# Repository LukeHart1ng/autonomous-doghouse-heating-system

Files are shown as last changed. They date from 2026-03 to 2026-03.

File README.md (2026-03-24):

# Autonomous Doghouse Heating System

A fully autonomous embedded temperature control system designed to regulate a 12V heating pad inside an outdoor doghouse. Built from the ground up — from requirements and schematic capture through custom PCB fabrication, firmware development, and structured verification testing.

## System Overview

The system activates a heating pad when ambient temperature falls between 0°F and 40°F and deactivates it when the temperature rises above that range. A secondary sensor monitors the heating pad surface and limits output if it approaches 115°F, preventing thermal overshoot. Heating intensity is regulated using a proportional PWM algorithm.

**Key specs:**
- Activation range: 0°F to 40°F (±2°F tolerance)
- Pad temperature limit: 115°F
- Activation response time: <30 seconds
- Sensor accuracy: ±2°F (verified against calibrated IR thermometer)
- Input power: 12V DC (compatible with battery or solar supply)
- Total system power: <50W

## Hardware Architecture

| Component | Part | Purpose |
|---|---|---|
| Microcontroller | MSP430FR2310 | Control logic, ADC, PWM generation |
| Temperature sensors | TMP36 (x2) | Ambient air + heating pad surface |
| Power switching | AO3400A N-channel MOSFET | Low-side switch for heating pad |
| Power regulation | LM2594MX-3.3 buck converter | 12V → 3.3V for MCU and sensors |
| Heating element | 12V DC heating pad | Primary heat source |
| Protection | 4A fuse (load), 100mA fuse (logic) | Overcurrent protection |

Custom PCB designed in Altium Designer. Two-layer board integrating power regulation, microcontroller, dual sensing, and MOSFET switching into a single compact footprint.

## Firmware

Written in C for the MSP430FR2310 using Code Composer Studio. Key functions:

- `readTemperature()` — triggers ADC conversion on selected channel, converts raw ADC value to °F using TMP36 transfer function (10mV/°C, 500mV offset at 0°C)
- `controlHeater()` — evaluates ambient and pad temperatures against thresholds, calculates proportional PWM duty cycle
- `setPWM()` — configures Timer_A PWM output on P1.2; fully disconnects peripheral and drives pin low when duty cycle is 0 to ensure MOSFET is reliably off

## Verification Results

All specifications verified through structured testing across freezer, refrigerator, and outdoor environments.

| Specification | Requirement | Result |
|---|---|---|
| Sensor accuracy | ±2°F of reference | Max observed error: 0.7°F — PASS |
| Activation response | <60 seconds | Range: 5–25 seconds — PASS |
| Deactivation response | <60 seconds | Range: 8–35 seconds — PASS |
| Activation range | 0°F–40°F ±2°F | Correct in all 12 trials — PASS |

Full verification data and subsystem documentation available in `Final_Product_Report.pdf`.

## Repository Contents

| File | Description |
|---|---|
| `main.c` | MSP430 firmware source code |
| `TopFinal(Circuit Diagram).SchDoc` | Altium schematic |
| `TopFinal.PcbDoc` | Altium PCB layout |
| `TopViewPCB.png` | PCB layout top view |
| `Final_Product_Report.pdf` | Full design and verification report |

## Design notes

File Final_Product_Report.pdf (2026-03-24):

# Electrical and Computer Engineering Montana State University (MSU)

EEL 489R -- Electrical Engineering Design II XX.XX.2025
Senior Capstone Final Project Report

# Temperature Activated Heating System

Design Engineers:
Lucas Harting

Project Customer:
Corey Mettler
Electrical and Computer Engineering Faculty

Final Project Report

Signature Page

Prepared By

### _________________________ _______

Lucas Harting | XX.XX.2025

Approval:

_______________________________ _______
Senior Engineer: {advisor’s name} Date
I certify that this document is ready to be sent to the project client provided that the requested changes/edits within are made and the course instructors also approve delivery.

# Executive Summary

Montana State University Electrical & Computer Engineering Department Lucas Harting
Team 16a

This project presents the design, fabrication, and verification of a fully autonomous doghouse heating system that activates based on ambient temperature to provide thermal comfort for outdoor animals in cold environments. The initiative addresses an often-overlooked need: in many communities, domestic dogs are exposed to prolonged subfreezing conditions in uninsulated shelters. Such exposure poses risks to animal health, including hypothermia and frostbite, particularly for short-haired breeds, senior animals, or those in poor health. Existing heating solutions often rely on continuous operation, manual switching, or expensive infrastructure, making them impractical or unsafe for widespread use.
The objective of this project was to develop a low-cost, energy-efficient, and autonomous heating system that activates within a specific temperature range (0°F to 40°F) and automatically deactivates when the ambient temperature rises above that threshold. To achieve this, the system was designed around a closed-loop feedback control architecture that continuously monitored environmental conditions and adjusted heating output accordingly. A heating pad was selected as the primary heating method because it delivers localized warmth efficiently without the need to heat the entire air volume of the doghouse, minimizing energy waste. The system’s control logic incorporated pulse-width modulation (PWM) to regulate the power sent to the heating pad, allowing smoother temperature control, reduced energy consumption, and safer operation as the pad approached its thermal limit. Paired with two temperature sensors, the system measures both the temperature of the ambient air as well as the surface temperature of the heating pad.
The heating system was successfully constructed on a prototyping platform and tested across a range of controlled environments, including freezers, refrigerators, and outdoor conditions, to simulate realistic winter scenarios. A detailed verification plan was created to evaluate system performance against key functional requirements: activation timing, temperature control accuracy, heating effectiveness, and safety margins. The results demonstrated that the system consistently activated heating when ambient temperatures fell within the target range and deactivated once the environment warmed beyond the threshold, confirming that the control strategy functioned as intended.
Temperature readings remained within ±2°F of external reference measurements, validating the accuracy and reliability of the sensing and control subsystems. All activation and deactivation events occurred well within the one-minute maximum response time requirement, and temperature regulation was maintained safely as the pad approached its designed maximum of 115°F. These results collectively confirm that the design meets its functional requirements.
Beyond technical performance, the system demonstrates real-world scalability and flexibility. It is adaptable for off-grid deployment scenarios when paired with alternative power sources and has broader potential applications in kennels, animal shelters, and livestock enclosures. Furthermore, the project establishes a solid foundation for future development, with planned enhancements such as wireless monitoring, mobile app control, remote data access, and additional safety features. Overall, the project successfully met all defined objectives and specifications. It provides a validated engineering solution to a critical animal welfare issue, offering a practical, affordable, and autonomous system for improving outdoor animal comfort in cold environments. The deliberate design choices made throughout development— emphasizing precise feedback control, efficient localized heating, and safe autonomous operation—ensured that the final product performs reliably and lays strong groundwork for future innovations in autonomous environmental control systems.

# Table of Contents

Page

SIGNATURE PAGE | II
EXECUTIVE SUMMARY | III
TABLE OF CONTENTS | IV
1. 7
1.1 | 7
1.2 | 7
1.3 | 7
1.3.1 | 8
1.3.2 | Error! Bookmark not defined.
1.3.3 | 11
2. 13
2.1 | 13
2.2 | 14
2.3 | Error! Bookmark not defined.
2.4 | 14
3. 14
3.1 | Error! Bookmark not defined.
3.1.1 | Error! Bookmark not defined.
3.1.2 | Error! Bookmark not defined.
3.2 | Error! Bookmark not defined.
3.2.1 | Error! Bookmark not defined.
3.2.2 | Error! Bookmark not defined.
3.3 | Error! Bookmark not defined.
3.3.1 | Error! Bookmark not defined.
3.3.2 | Error! Bookmark not defined.
4. Error! Bookmark not defined.
4.1 | Error! Bookmark not defined.
4.2 | Error! Bookmark not defined.
4.3 | Error! Bookmark not defined.
4.4 | Error! Bookmark not defined.
5. Error! Bookmark not defined.
5.1 | Error! Bookmark not defined.
5.2 | Error! Bookmark not defined.
6. Error! Bookmark not defined.
7. Error! Bookmark not defined.

## 1. Introduction

### 1.1 Project Motivation

Bozeman, Montana is home to many residents who have canine companions, creating a strong community of pet lovers. However, the region is also characterized by rapidly varying and often harsh weather conditions, including a wide temperature range. This can make it extremely difficult to keep dogs comfortable during inclement weather.

While traditional doghouses provide basic shelter, they often do not offer sufficient insulation or temperature control to keep dogs comfortable during cold weather. Therefore, there is a clear need for an advanced heating solution specifically designed to enhance the thermal comfort of dogs in cold climates. By developing a doghouse equipped with an autonomous heating system that maintains optimal temperatures, the project will directly address the needs of pets in Bozeman’s challenging winter conditions.

### 1.2 Project Description

Traditional doghouses often fall short in providing adequate comfort for dogs, especially during cold weather. To address this challenge, a specialized heating system will be developed that autonomously maintains optimal temperatures within a doghouse, ensuring comfort for dogs. This system will operate independently, focused solely on heating to keep the internal environment of the doghouse warm when the temperature drops below a predefined threshold. The project aims to activate the heating system based on real-time temperature monitoring, prioritizing the well-being of the dog. By leveraging efficient energy use, this approach seeks to deliver a reliable and sustainable solution for maintaining warmth in doghouses during cold seasons.

### 1.3 Project Background

To comprehensively understand the heating system project for doghouses, the following sections will provide background information exclusively related to the development and implementation of autonomous heating systems. Areas of interest include microcontroller applications for temperature regulation, and the specifics of heating systems suitable for doghouse environments. The following will offer a detailed analysis of the project considerations for effectively maintaining optimal comfort for dogs through a dedicated heating system.

### 1.3.1 Initial State of the Project [AI]

The focus of this project addresses a significant shortfall in traditional doghouse designs, particularly in their inability to provide thermal comfort during winter conditions. The sponsor, the Electrical and Computer Engineering Department at Montana State University, recognizes the need for a doghouse that can maintain an optimal and safe temperature to enhance the comfort of dogs living outdoors. Given Bozeman, Montana’s extreme winter conditions, with temperatures often remaining below freezing, there is need for a doghouse heating system that operates efficiently and autonomously to protect dogs from the cold.[1]

A proposed heating system is designed to endure the cold climate that is typical of northern regions. The device must function reliably in a range of environmental conditions including snow, ice, wind, and sub-zero Fahrenheit temperatures. This involves maintaining operational integrity in the face of moisture and freezing conditions and ensuring that the heating system can autonomously adjust to changing temperatures to provide consistent warmth without manual intervention.

Originally, the project envisioned a comprehensive smart doghouse equipped with a microgrid system, ventilation, heating, and connectivity to a mobile application for remote monitoring. However, after reassessment of project goals, resources, and direct needs, the focus has been narrowed significantly. The current iteration concentrates on developing an autonomous heating system for outdoor doghouses. The shift in project structure allows the team to allocate resources more effectively and address the most immediate need—thermal regulation for outdoor doghouses. The scaled-down focus enhances project feasibility and ensures that primary objectives are met without dilution of effort.

While the scope of the project is confined to heating, the design accommodates future expansion possibilities. The system's architecture is laid out such that it could later be integrated into a more extensive smart doghouse system, which might include features such as renewable energy integration, enhanced ventilation, and mobile connectivity. This prospective system could communicate with an owner’s mobile device to provide real-time updates on the doghouse temperature environment and heating system status, thereby aligning with original project motivations.

The initial state of the project reflects a well-considered approach to meeting the sponsor’s needs within operational and environmental constraints. It sets a solid foundation for a focused development effort aimed at delivering a critical solution to enhance dog comfort in winter conditions. The project's adaptability in design ensures readiness for future enhancements, making it a sustainable and forward-looking endeavor.

### 1.3.2 Technology Review [AI]

A survey of commercially available heating systems for pet enclosures reveals several widely used solutions such as resistive heating mats, plug-in pad heaters, and thermally regulated pet beds. Notable examples include the K&H Lectro-Soft Outdoor Heated Bed and the ASL Solutions Dog Palace Floor Heater [2], [3]. While these products provide a baseline level of warmth for animals, they exhibit considerable limitations when evaluated for deployment in harsh, cold-climate environments such as Bozeman, Montana. In particular, issues arise in the areas of energy efficiency, durability, responsiveness to environmental conditions, and electrical safety.

Many existing systems operate with binary or fixed-output heat control, drawing constant power once activated regardless of ambient conditions. Temperature regulation is often accomplished using simple thermostatic switches embedded within the heating surface. These switches engage or disengage the heater at pre-set temperatures without continuous environmental sensing. As a result, heating performance tends to be either excessive or inadequate during transitional conditions. Such limitations present serious drawbacks in applications where energy availability is constrained or where over-temperature conditions pose a risk to animal safety.

The majority of products available on the market are designed for alternating current (AC) wall power. This restricts their applicability in remote or mobile environments where grid access may be unavailable or where battery power is preferred. Additionally, products that support direct current (DC) power typically do so through crude adapters and lack the necessary safety redundancies, filtering, and voltage regulation to operate reliably in unattended outdoor systems.

Another critical shortcoming is the absence of environmental hardening. Many commercially available heated pads are constructed with low-durability materials that degrade under extended exposure to water, snow, or ice. In environments such as Montana, where winter conditions can persist for months with temperatures dropping below −10 °F, these materials often fail, leading to loss of function or, in some cases, short circuit and safety hazards.

To address these deficiencies, a custom-designed autonomous heating system was developed for application in outdoor doghouses exposed to cold climates. The system introduces several innovations to improve efficiency, reliability, and responsiveness while ensuring safe operation in challenging conditions.

### 1.3.3 Dual-Sensor Feedback with Real-Time Control

The proposed system utilizes two analog temperature sensors (TMP36) configured to measure ambient air temperature and surface temperature of the heating pad, respectively. These sensors output a voltage linearly proportional to temperature at a scale of 10 mV/°C with a 500-mV offset at 0 °C. By employing a dual-sensor configuration, the system establishes a closed-loop feedback mechanism that allows for both condition monitoring and active control. The ambient sensor triggers the system to enter heating mode once the surrounding temperature drops below 40 °F, while the pad sensor provides a secondary layer of thermal protection, ensuring the surface does not exceed 115 °F. This implementation prevents thermal overshoot and ensures proportional heating behavior under dynamic environmental conditions.

### 1.3.4 Microcontroller-Based PWM Regulation

Core system logic is developed on an MSP430FR2310 microcontroller, which samples the analog output from both temperature sensors via its integrated 10-bit analog-to-digital converter (ADC). Control logic is implemented in firmware using conditional branches and scaling functions to determine the appropriate response. If the ambient temperature is within the defined operational window (0 °F to 40 °F), the microcontroller outputs a pulse-width modulation (PWM) signal on pin P1.2. This signal is used to modulate the gate of an AO3400A N-channel MOSFET, which acts as a low-side switch for the heating pad circuit.

The use of PWM allows the system to regulate power delivered to the heating pad by varying the duty cycle of the gate signal. This improves energy efficiency by avoiding full-power operation when lower heat levels are sufficient. The PWM method also reduces stress on the power system and extends the longevity of both the heating element and associated power electronics. The microcontroller operates on a 3.3 V rail and was selected for its ultra-low-power consumption, ensuring that overhead from the control logic does not significantly impact total system energy use.

### 1.3.5 Power Design and Protection

The heating system is powered from 12 V DC input, compatible with solar-charged battery banks or automotive supplies. A buck regulator (LM2594MX-3.3) is used to step down the input voltage to 3.3 V for use by the microcontroller and sensor subsystems. This switching regulator provides high efficiency and stable output voltage with minimal heat generation. Output filtering includes a 150 µH inductor and 0.1 µF capacitor to suppress ripple and transient noise.

To ensure system protection and reliability, the design incorporates multiple electrical safeguards. A 4 A fuse is placed in series with the heating pad’s power line to protect against overcurrent conditions that could arise due to short circuits or pad degradation. A 100 mA fuse protects the low-voltage control subsystem. Gate protection for the MOSFET is achieved using a 470 Ω resistor in series and a 10 kΩ pull-down resistor to prevent unintended switching during startup or idle states. These design elements align with standard electrical safety practices for embedded heating systems.

### 1.3.5 Operational Conditions

All selected components are rated for extended industrial temperature ranges (−40 °C to +125 °C). Signal and power traces on the PCB are designed to minimize EMI and voltage drop, and 18 AWG wire was used for all high-current paths to reduce resistive heating losses.

### 1.3.6 Applicable Standards

The heating system incorporates design elements aimed at ensuring compliance with UL 499, a standard for electrical heating appliances. UL 499 was chosen as it provides guidelines that cover safety, performance, and reliability. Adhering to these standards is essential for providing safety for any device intended for the usage of animals.[8]

Adhering to UL 499 means that the circuit design incorporates appropriate spacing between conductive elements such as the high voltage supply (12V) and the low voltage supply elements (3.3V). The design prevents electrical shorts that could lead to fires that could be dangerous to users. Components such as a metal-oxide-field-effect transistor (MOSFET) and temperature sensors (TMP36) have all been chosen due to their ability to withstand high currents and high voltages, thereby providing a large safety margin. The design utilizes two TMP36 temperature sensors to monitor both ambient and heat pad temperatures. This allows the system to adjust based on two different temperature sensors data, allowing for the system to ensure that the components do not get too hot for usage and maintain a comfortable temperature for any dog utilizing the heating system.

The heating system utilizes two fuses, one 4A fuse and one 100mA fuse. Both fuses protect their respective elements from any overcurrent. This protection allows the heating system to safely shut off if overcurrent occurs. 470Ω and 10kΩ resistors are specified above the maximum expected operating conditions. This ensures long-term reliability without component failure.

The system considers IP ratings for moisture and dust resistance, ensuring that critical components such as the microcontroller, heating elements, and power supply are adequately protected from environmental exposure. Given the outdoor application, a minimum rating of IP65 is recommended to prevent moisture and dust, which could compromise electrical functionality over time.
By adhering to these standards, the heating system will meet industry safety and performance regulations while ensuring the longevity and reliability of the system under real-world conditions.

## 2. Project Requirements

The primary objective of this project was to develop an autonomous heating system for doghouses, designed to ensure the comfort and safety of dogs during the cold seasons in Bozeman, Montana. This goal stemmed from a clear need identified by our sponsor, who highlighted the inadequacies of traditional doghouses in maintaining suitable temperatures during winter months. The system was required to autonomously regulate the internal temperature of a doghouse, keeping it within a specific temperature range to optimize comfort without manual intervention. Beyond merely providing warmth, the heating system was engineered to be energy-efficient, safe, and reliable under varying environmental conditions. This initiative promised to enhance the well-being of dogs by providing consistently warm shelter, thus improving their quality of life during extreme weather conditions.

### 2.1 Product Requirements Outline

Obj 1) System will improve comfort within the doghouse based on external temperature conditions.
Req 1.1) System will autonomously heat the doghouse when temperatures are too cold.
Spec 1.1.1) | System will heat while the temperature in the doghouse is
| measured to be between 0 °F and 40 °F with a 2 °F tolerance.
Spec 1.1.2) | System will begin heating within 1 minute of the doghouse
| temperature measuring between 0 °F and 40 °F.
Spec 1.1.3) | System will stop heating within 1 minute of the doghouse
| temperature exceeding 40 °F with a 2 °F tolerance.
Req 1.2) System will monitor the temperature of doghouse
Spec 1.2.1) | Components will remain undamaged when temperatures range
| from –10 °F to 120 °F.
Spec 1.2.2) | Temperature will be measured within 2 °F of the actual measured
| temperature.

### 2.2 Design Constraints

1. All pets will be protected from any electrical or mechanical hazards.
2. System will be installed in this doghouse https://www.amazon.com/YITAHOME-Insulated-Doghouse-Resistant-Assembly/dp/B0BL2ZWG11.
3. The system will consume no more than 50 Watts per hour. *An original constraint before the group split up was to be power efficient. This constraint makes sure that the heating system remains efficient.

### 2.3 Additional Project Requirements or Deliverables

No additional level two requirements were introduced beyond the core system requirements outlined in section 2.1. The scope of the project remained consistent throughout development, focusing on the implementation of a functional and autonomous heating system.

### 2.4 Team Member and Project Responsibilities [AI]

The project tasks for the autonomous heating system for doghouses were entirely undertaken by Lucas Harting due to a reorganization of the team structure from the initial project conception. This transition to a single-member team necessitated a comprehensive approach, where Lucas was responsible for all aspects of the project, encompassing the ideation, design, implementation, and verification stages.

Lucas Harting was responsible for the complete system design, which included selecting appropriate components such as the MSP430 microcontroller, TMP36 temperature sensor, and heating elements. He also developed the circuit and wrote the embedded software to control the heating mechanism based on temperature readings. The design process involved creating a schematic diagram, selecting energy-efficient and safe components to meet the project’s requirements, and ensuring the system’s operational effectiveness in varying temperatures.

In addition to designing the system, Lucas also took on the role of testing and verifying the functionality and reliability of the heating system. This involved setting test conditions that mimicked the harsh winter environment of Bozeman. He conducted a series of tests to ensure the system operated within the defined temperature ranges and responded correctly to temperature fluctuations. The testing process also included safety verifications to ensure that the system did not pose any hazards under normal and fault conditions.

## 3. Subsystem Design and Verification

This design consists of a modular, autonomous heating system intended to maintain a comfortable environment based on external temperature conditions. The system is divided into three subsystems: temperature monitoring, control logic, and power-regulated heating output. Each of these systems is integrated into a printed circuit board (PCB) to ensure durability and stability. The block diagram shown below in Figure 3.1 titled Heating System Block Diagram, reflects updates since the critical design review (CDR). The diagram shown below in Fig. 1 presents the conceptual layout of the system.

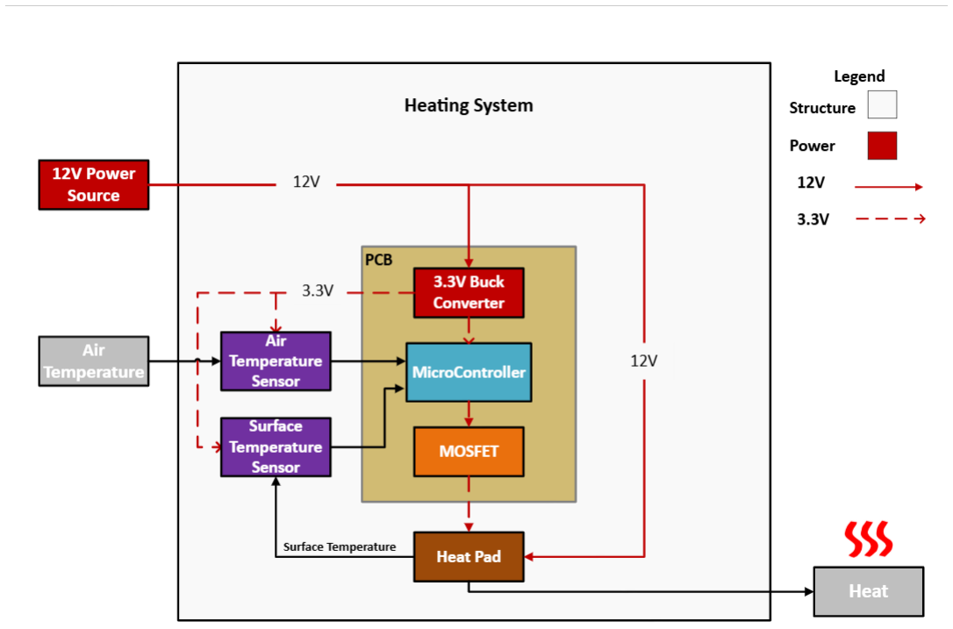
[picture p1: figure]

Figure 3.1 Heating System Block Diagram

### 3.1 Subsystem 1: Temperature Sensing and Monitoring [Lucas Harting]

The “Temperature sensing and Monitoring” subsystem is responsible for collecting temperature data and using this data to influence the behavior of the heating system. This includes 2 temperature sensors, an ambient air temperature sensor and a surface temperature sensor that actively monitors the temperature of the heating pad ensuring it does not get too hot for use. The two temperature sensors are powered with 3.3V stemming from a buck converter connected to a 12V power source.

### 3.2 Temperature Sensing

The temperature sensing subsystem provides the real-time temperature data necessary for the decisions of the control subsystem. The design required two separate measurements: An ambient internal temperature of the doghouse and the surface temperature of the heating pad. These readings are used to verify whether the interior of the doghouse is within the comfort range and whether the heating pad is operating at a comfortable and safe temperature.

To meet these needs, the TMP36 analog temperature sensor was selected. The diagram, shown below labeled Figure 3.2 TMP36 Pinout, was chosen for several reasons. It offers a simple analog interface,
It has an operating temperature range of -40°C to 125°C, suitable for the cold winters of Bozeman, Mt. It is also low-cost and has low quiescent current (<50 µA), which aligns with the power constraint of ≤50W.

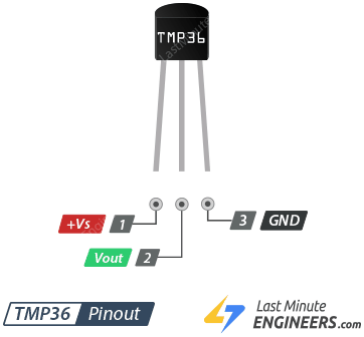
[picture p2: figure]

Figure 3.2 TMP36 Pinout

Each TMP36 temperature sensor outputs a voltage proportional to the ambient temperature, at a scale of 10 mV/°C, with a 500 mV offset at 0°C. The analog output is read by the 10-bit ADC module built into a microcontroller. The conversion process involves measuring the voltage at each sensor and converting it into a digital value, which is then processed via a conversion function that compensates for the offset and returns the temperature in °F. To ensure signal integrity and accurate ADC readings, a 0.1 µF ceramic capacitor is placed between the V_IN (Pin 1) and GND (Pin 3) of each TMP36. This capacitor acts as a decoupling filter, suppressing high-frequency noise from the power supply and stabilizing the operating voltage.

Both sensors are powered from the 3.3V power output generated by a buck converter (LM2594). The heat pad temperature sensor is connected via 18-gauge wire routed to the PCBs sensor terminal while the ambient air temperature sensor is soldered directly on the PCB itself. The heating pad draws up to 3.2A and 18 AWG wire offers a safe current rating of approximately 5A, providing ample margin.

### 3.3 Temperature Sensing and Monitoring Fabrication and Verification

Initial sensor circuits were built on a breadboard and verified independently before integration. The system was subjected to a range of environmental temperatures from -4°F to 120°F using a freezer setup to measure the lower bound and upper bound of the temperature spectrum respectively. By placing the system within the freezer one is able to achieve lower temperatures than in a traditional indoor environment. The freezer was set to approximately 0°F. By placing the system within different locations of the freezer different temperatures were achievable. For higher temperatures but still those below 40°F, the system was placed in a refrigerator to simulate colder temperatures but not freezing temperatures. Sensor readings were compared against an external IR thermometer to evaluate accuracy.

Verification Test: Spec 1.2.2
- Purpose: Confirm that TMP36 sensors measure temperature within ±2°F of a calibrated IR thermometer. The temperature sensor in question made by Ames Instruments is calibrated to be accurate within 2°F of actual temperature.
- Equipment: TMP36, IR Thermometer, MSP430, 3.3V power supply.
- Conditions: 5 trials ranging from -4°F to 120°F.
Trial | TMP36 (Ambient) | IR (Ambient) | TMP36 (Pad) | IR (Pad) | Result
1 | 62.6 °F | 63.2°F | 64.4°F | 63.5°F | PASS
2 | 30.2°F | 29.5°F | 32.0°F | 31.1°F | PASS
3 | 55.4°F | 55.9°F | 4.2°F | 4.9°F | PASS
4 | 120.6°F | 121.3°F | 57.2°F | 57.7°F | PASS
5 | -4°F | -3.3°F | 109.4°F | 109.9°F | PASS
Figure 3.3 Spec 1.2.2 Data

This verification test of spec 1.2.2 proved that the TMP36 was a good choice for the design. Across all five trials both the TMP36 temperature sensors and the external IR temperature sensor remained well within the 2 °F tolerance. With the maximum observed error being 0.7 °F, this validates both the accuracy and calibration of the sensors. This confirmed that the sensing subsystem meets specification 1.2.2 and can reliably serve as the basis for temperature related control decisions.

### 3.4 Control Logic and Decision-Making [Lucas Harting]

The control logic subsystem is the core of the system, shown below in Figure 3.4. It interprets the analog temperature signals and compares those signals to the predefined threshold. This logic is implemented in firmware on the MSP430FR2310 microcontroller and consists of analog to digital conversion, conditional temperature checks, and pulse width modulation (PWM) output.

The firmware begins with initialization, setting digital and analog input/output pins, configuring the ADC module, and defining system thresholds. The ambient temperature sensor, configured to P1.1, the heat pad temperature sensor configured to P1.2, and the PWM output to heating pad via a field-effect transistor (MOSFET) is configured to P1.3. Shown below is figure 2 highlighting the control logic of the system. A threshold of 0°F to 40°F defines the system operational range. Below 0°F the system will remain off. Above 40°F the system will also remain off. When the temperature is measured to be between 0°F and 40°F the system will turn on using PWM to adjust the temperature of the heat pad ensuring an efficient and safe operation. A stabilization delay of 1 second is introduced to allow thermal changes and avoid excessive switching.

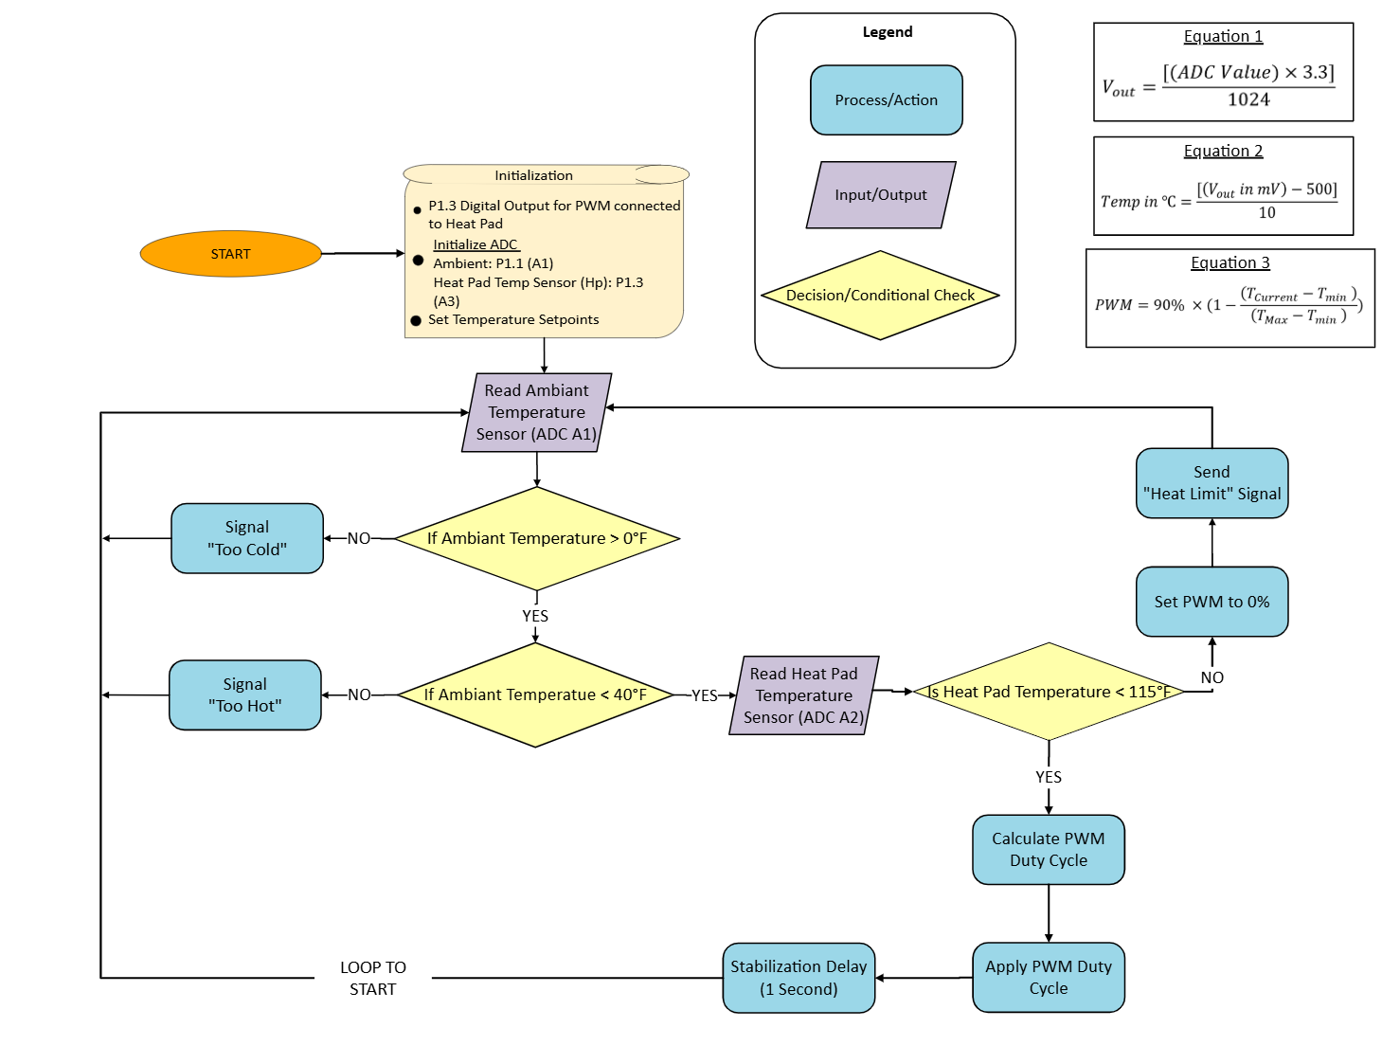
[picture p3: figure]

Figure 3.4. Design Logic

The heating intensity is adjusted using a proportional PWM output depending on the ambient temperature. This is shown above in equation 3 where T current is the current ambient temperature, Tmin is the activation threshold (0°F) and Tmax is the deactivation threshold (40°F).

### 3.5 Control Logic and Decision-Making Verification

The control logic subsystem was verified through experimental testing. The purpose of this verification was to ensure that the MSP430 microcontroller correctly interprets temperature inputs and triggers heating activation and deactivation within system specifications. Verifying spec 1.1.2 – Heating activation within 1 minute of the system measuring within activation range. The ambient temperature sensor was placed in a variety of environments measuring within and outside of activation range. A temperature of around 40°F was acquired by simply opening a household door while it was cold outside. Colder temperatures were met utilizing a household freezer. An LED would turn on when the system was sending power to the MOSFET indicating that the heating pad would be operational. A timer was utilized to measure the time between when the system would measure within activation bounds and when the LED light would turn on. The system passed this spec with no outliers. The data shown below represents the results of the trial.

Trials | Temperature of activation | Time of activation after temperature reaches 0°F to 40°F
Trial 1 | 39.2 °F | 10-12 seconds
Trial 2 | 39.2 °F | 1-3 seconds
Trial 3 | 37.4 °F | 15-17 seconds
Trial 4 | 39.2 °F | 5-7 seconds
Trial 5 | 41°F | NA
Trial 6 | 1.4°F | 8-10 seconds
Trial 7 | -0.4°F | 10-12 seconds
Trail 8 | 1.4 °F | 1-3 seconds
Trial 9 | 3.2 °F | 8-10 seconds
Trial 10 | 1.4 °F | 5-7 seconds
Figure 3.4. Spec 1.1.2 Data

In all trials, the heating was initiated well under the 60-second requirement. The non-activation case’s occurred when the ambient temperature was outside the heating range (41.0°F), demonstrating correct logical boundaries. This verifies compliance with spec 1.1.2.

Spec 1.1.3: Heating deactivates within 1 minute when ambient temperature exceeds 40°F. The objective of this test was to confirm that the system operates as intended. To measure the upper bounds the system was simply placed in a room temperature house (around 67°F). Similar to 1.1.2, the timer will start when the temperature measured by the system exceeds 40°F. The timer will then stop when the LED turns off signaling that power has been cut off and that the PWM is set to 0%. The results of the trial are shown below.

| Ending Temp (°F) | Time of de-activation after temperature exceeds 40°F.
Trial 1 | 42.8 °F | 33-35 seconds
Trial 2 | 41 °F | 5-7 seconds
Trial 3 | 44.6 °F | 23-25 seconds
Trial 4 | 41 °F | 10-12 seconds
Trial 5 | 41 °F | 18-20 seconds

Figure 3.5. Spec 1.1.3 Data

The results concluded that the system consistently deactivated heating well within 60 seconds of exceeding the specified temperature range. In all trails, the microcontroller reliably transitioned the PWM signal to 0% meeting Spec 1.1.3.

### 3.6 Heating Output and Power Regulation [Lucas Harting]

The heating output of the system is responsible for delivering heat to the doghouse interior via a heating pad. A heating pad was chosen for this application due to its low current draw, broad thermal range, and compatibility within the doghouse. Power to the heating pad is switched using a MOSFET (A03400A) which acts as an electronic switch controlled via a PWM signal from the MSP430. When the microcontroller sets the MOSFET gate high, current will flow from the 12V power supply through the heating pad to the ground enabling heat. The PWM signal allows for heat output control based on both the ambient air temperature and the surface temperature of the heating pad.

A fuse is included in-line with the 12V power source to protect the system in the event of a short circuit or overcurrent condition. This 4A fuse provides adequate protection while supporting the power demands of the heating pad. Both the heating pad and the power source are connected via MOLEX 2 pin plugs. This allows the user to unplug the power source and heat pad at will if their needs demand this. This also allows the system to be more maneuverable. Both the heating pad and power source are connected via 18 AWG wire allowing for current draw without the wire being too cumbersome and remaining cost effective.

### 3.6.1 Heating Output Fabrication and Verification

Shown below in Fig 3.6. Heating System Circuit Schematic, the heating output was evaluated in conjunction with the control logic. Initial bench testing verified that the MOSFET fully turned on (saturation mode) when a signal was applied and fully blocked current when the gate was low. A multimeter was used to confirm voltage levels at the gate, drain, and source under different operating conditions. The pad was also tested separately, ensuring that when plugged into a 12V power source the heating pad turns on reliably. This was confirmed true by utilizing an external IR temperature sensor to monitor the warmup of the pad. Req 1.1: System will autonomously heat the doghouse when temperatures are too cold, confirms that the system operates as expected with the following results. The system with the heating pad was placed in an environment within its activation range and the temperature of the heating pad was monitored to ensure that it turned on and functioned as expected.

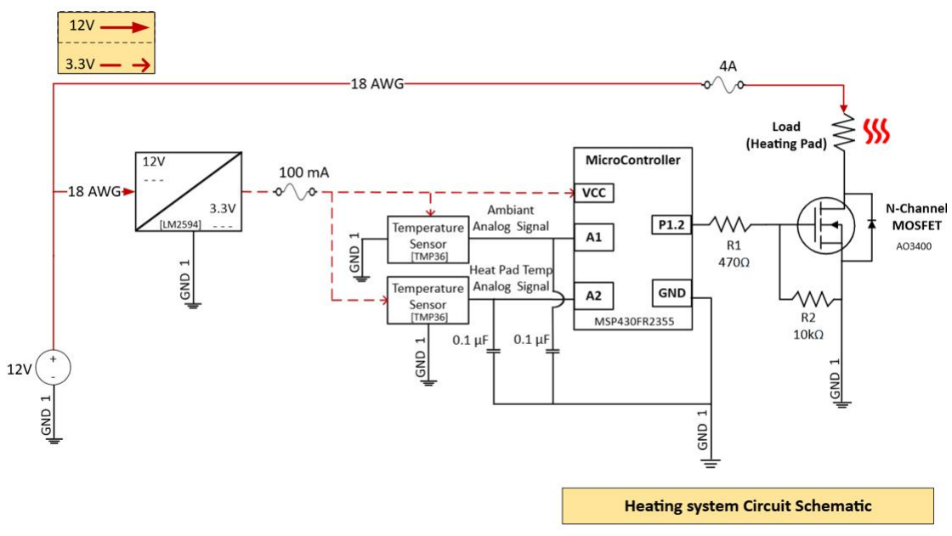
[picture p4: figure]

Figure 3.6. Heating System Circuit Schematic

| Ambient Temp of Activation (°F) | Starting heatpad Temp (°F) | Ending heatpad Temp (°F)
Trial 1 | 1.4°F | 63.3°F | 78.6°F
Trial 2 | 4.4°F | 65.4°F | 82.2°F
Trial 3 | 1.4°F | 13°F | 53.2°F
Trial 4 | 3.2°F | 65.0°F | 86.6°F
Trial 5 | 21.2°F | 66.7°F | 102.0°F
Trail 6 | 32.0°F | 33.8°F | 96.7°F
Trial 7 | 33.7°F | 42.0°F | 78.3°F
Trial 8 | 37.4°F | 33.2°F | 84.5°F
Trial 9 | 39.2°F | 36.7°F | 108.6°F

Figure 3.7. Req 1.1 Data

The following results indicate that when the system was within operational range of 0°F to 40°F the heating pad temperature increased, indicating that the heating pad was functioning as expected via the rest of the system. The heating output subsystem reliably and safely delivered variable heat in response to system control.

## 4. System Fabrication and Verification

The final stage of the project focused on fabricating the fully integrated heating system and validating its performance under realistic operating conditions. This chapter provides a comprehensive evaluation of the completed system’s ability to meet Objective 1. "System will improve comfort within the doghouse based on external temperature conditions" along with all underlying specifications and requirements.

As the subsystems were fabricated, verified, and fully tested in isolation, they were integrated into the complete autonomous heating system. This finalized system was capable of sensing temperature, and making decisions based on thresholds, and regulating heating output. This block diagram outlines how the temperature sensors gather analog environmental data and feed it into the MSP430FR2310 microcontroller, which uses embedded control logic to interpret the values and issue a PWM signal to control an N-channel MOSFET. This MOSFET acts as a gate for current flowing from the 12V supply to the heating pad. A buck converter steps down the voltage to 3.3V for the microcontroller and sensors, maintaining efficient power distribution.

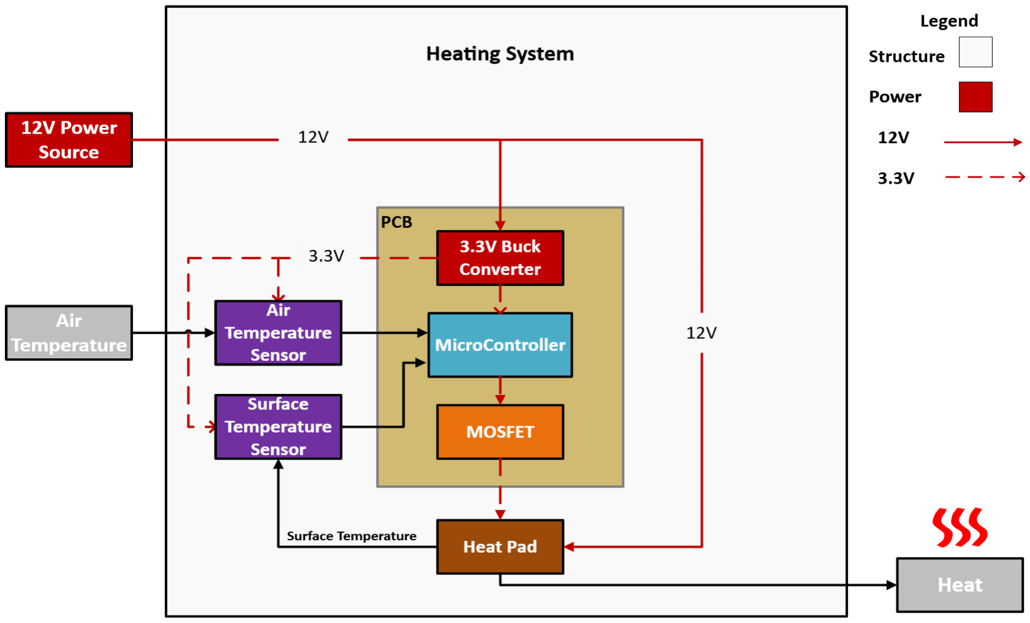
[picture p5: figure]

Figure 4.1. Final Conceptual Block Diagram

### 4.1. System Design

Analysis of this system can be further explained through figure 4.2, the circuit diagram detailing the final system. The heating subsystem circuit is designed to regulate a low-voltage heating pad using real-time temperature feedback from two analog sensors, all powered by a single 12V DC input. At the core of the power distribution network is a buck converter, which steps the 12V supply down to 3.3V to power the MSP430FR2310 microcontroller and the two TMP36 temperature sensors. The LM2594 also includes a 150 µH inductor and a 0.1 µF capacitor on the output for voltage stability and noise suppression. The 3.3V rail ensures safe and reliable operation of the logic circuitry and analog signal conditioning. Following the completion of individual subsystem verification, the full system was fabricated by soldering all active and passive components onto a two-layer PCB designed in Altium Designer. The board incorporated three major functional blocks: (1) temperature sensing, (2) embedded control and PWM generation, and (3) heating output with power regulation.

Temperature data is collected through two TMP36 sensors, one placed to measure ambient air temperature and the other to monitor the heating pad surface. These analog sensors output voltage signals proportional to the measured temperature, which are fed into the microcontroller’s ADC channels (A1 and A0). Each sensor is paired with a 0.1 µF decoupling capacitor to minimize electrical noise and ensure accurate readings.
The MSP430FR2310 microcontroller processes this data and determines whether heating is required based on programmed logic conditions. If the system detects that heating is necessary, it sets the digital output pin P1.2 to a high logic level, which in turn activates an N-channel MOSFET (AO3400A). This MOSFET serves as a switch, allowing the 12V supply to power the heating pad when its gate is driven high. A 470Ω resistor (R1) is placed in series with the gate to limit the inrush current and protect the microcontroller from damage due to capacitive loading. Additionally, a 10kΩ pull-down resistor (R2) is connected between the gate and ground to ensure the MOSFET reliably turns off when P1.2 is not actively driven high.

To handle the load required by the heating pad, all high-current connections are routed using 18 AWG wire, which provides sufficient current-carrying capacity with minimal voltage drop. A single ground reference, labeled GND_1, is shared across all components—including sensors, logic circuitry, and power elements—to maintain signal integrity and consistent voltage levels throughout the system. This carefully coordinated design enables reliable, safe, and efficient temperature-based control of the heating element within the doghouse environment.

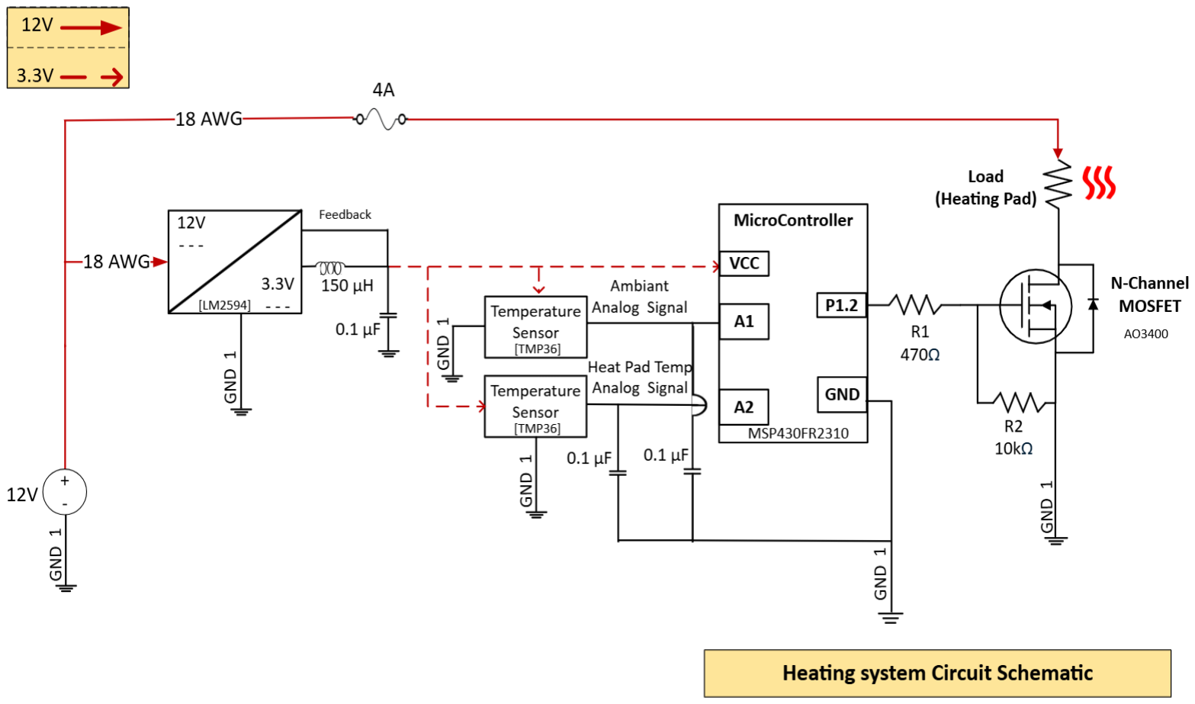
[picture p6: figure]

Figure 4.2. Heating System Circuit Schematic

### 4.2. System Control Logic

Figure 4.3, shown below, illustrates the logic embedded within the MSP430FR2310. The control logic for the doghouse heating system is governed by a structured decision-making loop implemented on the MSP430FR2310 microcontroller. Upon initialization, the microcontroller configures its P1.2 pin as a digital output for Pulse Width Modulation (PWM), enabling it to regulate power delivery to the heating pad via an N-channel MOSFET. Analog-to-digital conversion (ADC) is initialized for two TMP36 temperature sensors: one measuring ambient air temperature connected to pin P1.0 (A0), and the other monitoring the heating pad’s surface temperature connected to pin P1.1 (A1). The system defines critical temperature thresholds to guide operations specifically, an ambient lower limit of 0°F, an upper activation threshold of 40°F, and a maximum allowable pad temperature of 115°F to prevent overheating.

During each loop cycle, the microcontroller first reads the ambient temperature using the TMP36 sensor and evaluates whether the current environment warrants heating. If the ambient temperature is below 0°F, the system flags the condition as “Too Cold” and restarts the loop without engaging the heating pad. Conversely, if the temperature exceeds 40°F, it signals “Too Hot” and similarly refrains from heating. If the ambient temperature is within the 0°F to 40°F range, the system proceeds to read the temperature of the heating pad. If the pad is already at or above 115°F, the microcontroller sets the PWM duty cycle to 0%, effectively disabling the heating output and triggering a “Heat Limit” warning to prevent overheating. However, if the heating pad is below 115°F, the system calculates a PWM duty cycle based on a linear scaling equation, ensuring the pad gradually approaches the target temperature without overshooting.

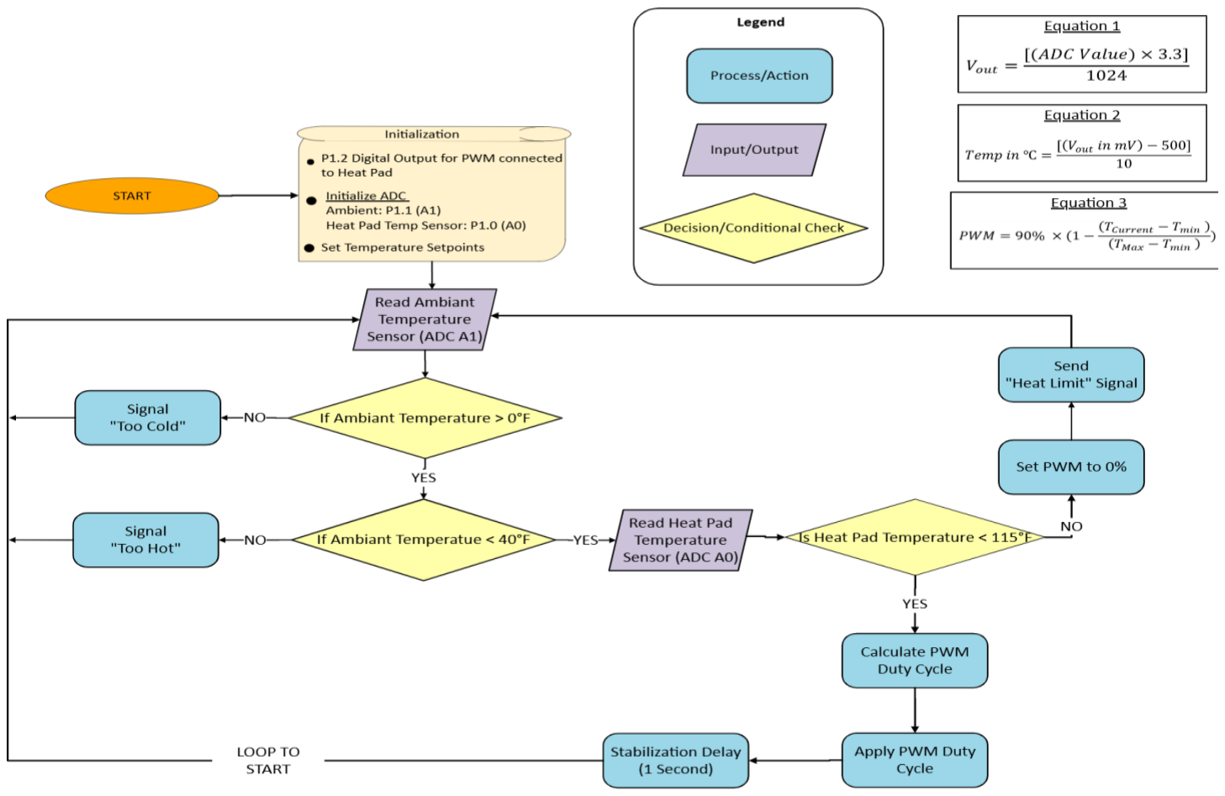
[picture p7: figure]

Figure 4.3 Control Logic

### 4.3 System Integration

System integration required careful planning of both signal and power paths. The temperature sensing subsystem, consisting of two TMP36 temperature sensors, was mounted on the PCB and routed to their target locations inside the doghouse using shielded 18-gauge wire to reduce noise pickup. The ambient TMP36 sensor was soldered directly to the PCB. The PWM TMP36 temperature sensor was placed against the heat pad with adhesive and routed to the PCB with 18-gauge wire. Their outputs were routed to ADC inputs on the MSP430 (P1.1 for ambient, P1.0 for pad).
The control logic subsystem was implemented through firmware running on the MSP430FR2310. Once the analog inputs were acquired and converted, the control logic computed whether the ambient temperature fell within the heating threshold range. The logic then calculated the proper PWM duty cycle and wrote it to the Timer_A module, which modulated the voltage to P1.2 connected to the MOSFET gate. This logic was verified with test voltages before integrating with the hardware.

For heating output, the low-side MOSFET was installed on the PCB to ensure thermal stability. It was connected between the heating pad and ground, with the pad’s positive lead tied directly to the 12V input.
The power regulation subsystem used an LM2594 buck converter, configured using a voltage divider to output 3.3V. The output rail supplied the MSP430, TMP36 sensors, and supporting passive components. To prevent damage, a 4A fuse was installed inline on the 12V rail prior to the heating element. Capacitors were distributed throughout the board to reduce electrical noise.
After individual verification of each component and functional block, the entire PCB was tested.

### 4.5 System Verification

Objective 1 is composed of 5 specifications and 2 requirements. Each specification and requirement were tested thoroughly to ensure that the systems comply with each. After assembling the system shown below, specification 1.2.2 was the first specification tested. Specification 1.2.2, stating “temperature will be measured within 2 degrees Fahrenheit of actual measured temperature” was relatively simple to measure. The test contained both the ambient and heat pad temperature sensors. A probe with one lead connected at the Vout pin of the TMP36 temperature sensor will be measured in reference to ground. The test contained 5 trials measured over a range of temperatures from subzero to around 110 degrees F. Repeating this test with the complete system ensures that the system was not affected by assembling the complete system. By testing each temperature sensor against the data of the IR sensor one is able to verify that the temperature readings of the TMP36’s are accurate. The following diagram of the TMP 36 temperature sensor has been provided for reference. In each of the 5 repeated trials, the temperature sensors measured within 2 degrees Fahrenheit of each other.

### 4.6 Specification 1.1.2. Verification

Specification 1.1.2 and 1.1.3 were tested next stating “system will begin heating within 1 minute of the doghouse temperature measuring between 0 degrees and 40 degrees Fahrenheit with a 2-degree tolerance” and “system will stop heating within 1 minute of the doghouse temperature exceeding 40 degrees Fahrenheit with a 2 degree tolerance” respectively. Specification 1.1.2 requires that the heating system not only activates within the correct temperature range but does so within one minute of crossing the threshold. This specification ensures timely response to environmental changes, particularly in cases where the temperature drops quickly.

The one-minute response requirement was derived from consideration of rapid temperature changes that an outdoor environment can face.
To validate this spec, eight trials were conducted using a freezer, outdoor environment, indoor air in conjunction with a refrigerator. The system was pre-cooled in a freezer to simulate below-threshold temperatures. A multimeter was used to measure the temperature of the ambient air temperature sensor. By placing the system within the activation threshold, the multimeter would be monitored to see exactly when the tmp36 temperature sensor first measured a temperature within activation range. Immediately a timer would be started with the multimeter quickly being placed on P1.2 of the microcontroller. When an output voltage was measured at P1.2 the timer would be stopped as this signaled that power was being sent to the heating pad producing heat. Across all eight trials, activation times ranged from 5 to 25 seconds. The delay was influenced by how quickly the temperature transitioned and stabilized within the operational range. Importantly, no trial approached the 60-second limit, and several trials saw activation within 10 seconds. This performance confirms that the ADC conversion, temperature comparison logic, and MOSFET triggering operate without latency or interrupt-driven delays.

Analyzing this from a system-level view, fast activation has two major implications. First, it validates the microcontroller’s ability to respond in near-real time to environmental inputs without hanging or buffering delays. Second, it demonstrates that the heating hardware is ready and energized as soon as logical conditions are met. This reliability supports the safety and comfort features of the design, especially in northern climates or for at-risk animals in low temperatures.

The results of this test strongly affirm that the feedback loop between sensing and control is robust, with no unnecessary delay or software-induced debounce errors. Additionally, this test helps validate the power-up and wake-from-sleep behavior of the microcontroller. The system proved capable of initializing and activating heating rapidly after detecting a valid condition, a key feature for real-world deployments in environments with fluctuating temperatures.

| Temperature of activation | Time of activation after temperature reaches 0 °F -40 °F±2 °F
Trial 1 | 37.4 °F | 15-17 seconds
Trial 2 | 35.6 °F | 18-20 seconds
Trial 3 | 39.2 °F | 15-17 seconds
Trial 4 | 39.2 °F | 5-7 seconds
Trial 5 | 41°F | 0 seconds
Trial 6 | 33.8°F | 15-17 seconds
Trial 7 | 10.4°F | 23-25 seconds
Trial 8 | 5.0°F | 8-10 seconds
Figure 4.5. Spec 1.1.2 Data

### 4.7. Spec 1.1.3. Verification

While activating the heating system within cold temperature ranges is essential, equally important is ensuring that the system deactivates as temperatures rise above the 40°F threshold. Specification 1.1.3 defines this requirement, stating that the system must turn off the heating pad within one minute of detecting an ambient temperature above 40°F ± 2°F. This ensures the doghouse does not overheat and conserves energy during transitional weather conditions.

To test this behavior, five trials were conducted. The system was initially stabilized within the operational temperature range (typically 30°F to 35°F), triggering the heating pad to activate. Once the system remained on for several minutes, it was then exposed to a controlled warm environment—typically an indoor space and a stopwatch was started once the TMP36 sensor reading crossed the 42°F threshold. As in the activation tests, a multimeter monitored the logic level of P1.2 to detect MOSFET deactivation.

All five trials showed consistent deactivation of the heating pad within 35 seconds after exceeding the temperature threshold. This indicates that the microcontroller’s logic correctly responds to changing inputs and ceases heating when conditions no longer require thermal output. At the system level, this is critical to prevent overheating of the internal enclosure and confirms that the system’s logic is reversible and dynamic, not reliant on hardcoded latch behavior or long decay times.

The implications of this result are significant. Firstly, it verifies that the control algorithm and temperature sensing mechanism not only trigger under correct conditions but also respond appropriately to the reverse condition. This reflects the closed-loop nature of the system, which continuously evaluates the environment to adapt its behavior. Secondly, by deactivating quickly, the system avoids unnecessary power consumption. In short, Specification 1.1.3 confirms that the heating subsystem exhibits proper termination behavior. Results demonstrate that the heating system remains not only functional but responsible in managing thermal delivery to the doghouse environment.

| Ending Temp (°F) | Time of de-activation after temperature exceeds 40°F.
Trial 1 | 41 °F | 8-10 seconds
Trial 2 | 42.8 °F | 21-23 seconds
Trial 3 | 42.6 °F | 15-17 seconds
Trial 4 | 41 °F | 33-35 seconds
Trial 5 | 41 °F | 18-20 seconds
Figure 4.6. Spec 1.1.3 Data

### 4.8. Specification 1.1.1. Verification

The next specification tested was specification 1.1.1 stating “system will heat while the temperature in the doghouse is measured to be between 0 degrees and 40 degrees Fahrenheit with a 2-degree tolerance.” Specification 1.1.1 ensures that the system activates the heating pad only when the ambient temperature is within the 0°F to 40°F operational range, allowing a tolerance of ±2°F. This specification was essential for validating the system's logic to prevent unnecessary heating in mild or warm conditions and to ensure activation in cold environments.

To verify this specification, twelve trials were conducted under a wide range of environmental conditions. Testing was performed in three temperature brackets: subfreezing temperatures (ranging from -4°F to 5°F using a freezer), mid-range cold temperatures (10°F to 35°F using refrigerator exposure), and near-threshold conditions (37°F to 45°F using controlled indoor environments).

During each trial, the system was powered on and left to stabilize for three to five minutes. The MSP430 microcontroller continuously monitored the ambient temperature via ADC input. When the sensed temperature was within range, pin P1.2 was expected to output a digital HIGH (3.3V), activating the MOSFET and thereby the heating pad. Voltage at P1.2 was monitored using a multimeter.
The recorded results indicated that in all twelve trials, the system activated the heater when the ambient temperature was within the expected bounds and deactivated it when outside the range. The controller consistently activated the heater below 40°F and deactivated it above 42°F, demonstrating correct implementation of the ±2°F tolerance range.

From a system-level perspective, this result confirms that the heating control logic and its interface with the temperature sensing circuit are functioning correctly. The ability to accurately switch heating states based on real environmental conditions ensures the doghouse will neither overheat in borderline conditions nor fail to activate when it's cold. Moreover, the successful boundary response confirms the analog-to-digital conversion and software filtering applied to temperature inputs are tuned well.

This test is also important in validating the logic of the embedded firmware. If the heating pad were to activate outside the specified range, the system could waste power or potentially make the internal environment uncomfortable. Conversely, failure to activate within range would compromise the primary objective of thermal comfort. The results show that the system balances these priorities effectively, behaving as designed and achieving the first critical step toward system-wide objective verification.

| Temperature of Environment °F (TMP36) | System ON/OFF | Pass Spec? YES/NO
Trial 1 | 53.6°F | OFF | YES
Trial 2 | 62.6 °F | OFF | YES
Trial 3 | 46.4°F | OFF | YES
Trial 4 | 37.4°F | ON | YES
Trial 5 | 28.4°F | ON | YES
Trial 6 | 28.4°F | ON | YES
Trial 7 | 21.2°F | ON | YES
Trial 8 | 10.4°F | ON | YES
Trial 9 | 6.8°F | ON | YES
Trial 10 | -0.4°F | ON | YES
Trial 11 | -4.0°F | OFF | YES
Trial 12 | 6.8°F | ON | YES
Figure 4.7. Spec 1.1.1 Data

### 4 .9. Requirement 1.1. Verification

Requirement 1.1 stating “System will autonomously heat the doghouse when temperatures are too cold” extends beyond isolated component behaviors and shifts focus on validating system-wide performance in cold-environment scenarios. This requirement ensures that the entire heating system—from sensor input to logic control, to actuation—functions autonomously when placed in an operational setting, such as an outdoor doghouse in winter. To validate this, the integrated system was tested across a range of environmental conditions to confirm that it could detect cold temperatures and engage the heating pad without manual input or intervention.

A total of nine trials were conducted for this test. The test environments ranged from extremely low ambient temperatures (down to 3.2°F) to borderline operational temperatures (near 39°F), and up to non-activation conditions (64.4°F and 66.2°F). The system was powered using a 12V DC source and monitored over a period of time using both a serial interface (to confirm logic state and temperature readings) and an external infrared thermometer (to confirm pad temperature behavior). Each trial measured three values: the ambient temperature at the time of activation, the initial heating pad temperature, and the final heating pad temperature recorded after 5–10 minutes of operation.

The results showed consistent heating behavior in every trial conducted under activation conditions. For instance, in Trial 1, the ambient temperature was 5.0°F, and the pad increased from 67.6°F to 112.9°F. In Trial 7, the ambient was 39.2°F and the pad still increased from 63.0°F to 117.3°F. Importantly, the system remained inactive during the high-temperature trials, such as Trial 8 (66.2°F to 67.0°F) and Trial 9 (64.4°F to 64.3°F), confirming correct deactivation logic.

From a system-level perspective, these results are significant because they demonstrate that the individual specifications—temperature detection, logic interpretation, and MOSFET actuation—are correctly coordinated. There were no observed misfires or logic errors during the test period. This means the MSP430 microcontroller reliably received sensor data, computed appropriate thresholds, and executed control signals consistently across the entire test range.

Furthermore, this test validates the system's readiness for unattended deployment. In a real-world scenario, the heating system would not be monitored or adjusted daily, so it must detect cold automatically and respond appropriately. The consistency and correctness of these trials suggest a high level of reliability, with the thermal behavior of the pad aligning well with environmental demands. The data confirms that the doghouse heating system performs its primary purpose: to autonomously deliver comfort in cold conditions.

| Ambient Temp of Activation (°F) | Starting Heatpad Temp (°F) | Ending Heatpad Temp(°F)
Trial 1 | 5°F | 67.6°F | 112.9°F
Trial 2 | 3.2°F | 68.0°F | 109.6°F
Trial 3 | 8.6°F | 64.3°F | 116.4°F
Trial 4 | 3.2°F | 65.9°F | 112.0°F
Trial 5 | 28.4°F | 62.2°F | 114.1°F
Trail 6 | 23.0°F | 64.0°F | 112°F
Trial 7 | 39.2°F | 63.0°F | 117.3°F
Trial 8 | 66.2°F | 67.0°F | 68.1°F
Trial 9 | 64.4°F | 64.3°F | 62.0°F

Figure 4.8. Requirement 1.1 Data

### 4.10. Requirement 1.2. Verification

While heating behavior is the primary function of the system, continuous temperature monitoring is a foundational support requirement. Requirement 1.2. stating “System Will Continuously Monitor the Temperature of the Doghouse” validates that the system is capable of consistently tracking ambient temperatures over time, ensuring that it remains aware of environmental shifts and capable of making informed control decisions. This requirement ensures that the system behaves predictably and responsively, especially in scenarios with gradually shifting thermal profiles.

To evaluate this requirement, four distinct trials were conducted, each within a unique temperature bracket to simulate the range of doghouse environmental conditions: above threshold (66.2°F), within threshold (28.4°F and 37.4°F), and near freezing (6.8°F). The system was placed in each of these environments for a 15-minute period, during which sensor readings were recorded every three minutes using a multimeter.

The results demonstrated reliable and stable data reporting across all trials. At each time interval, the system correctly reported increasing or decreasing trends in response to environmental changes. For example, in Trial 4 (6.8°F start), the sensor data captured a warming trend as the pad activated, showing values such as 6.8°F, 12.2°F, 8.6°F, and 15.8°F in successive samples. This confirmed that the sensors could continuously update readings and reflect actual changes in system temperature.

At the system level, this capability is essential to enable responsive feedback loops. Without continuous monitoring, the PWM logic or on/off thresholds could not be reliably triggered. Importantly, this test also verified system stability across extended operation, ruling out issues like signal drift, microcontroller hangs, or communication dropouts. This test also highlighted the temporal accuracy of the ADC sampling routine and showed that the firmware implementation on the MSP430 correctly manages periodic measurement tasks. Consequently, the system met and exceeded expectations for long-term environmental tracking, which is key for maintaining animal comfort and safety in an autonomous deployment.

| System measured Temperature (°F) Trial 1 | System measured Temperature (°F) Trial 2 | System measured Temperature (°F) Trial 3 | System measured Temperature (°F) Trial 4
Minute 0 | 66.2°F | 28.4°F | 37.4°F | 6.8°F
Minute 3 | 64.4°F | 28.4°F | 35.6°F | 12.2°F
Minute 6 | 66.2°F | 30.2°F | 35.6°F | 8.6°F
Minute 9 | 68.0°F | 32.0°F | 33.8°F | 15.8°F
Minute 12 | 68.0°F | 30.2°F | 35.6°F | 12.2°F
Minute 15 | 69.8°F | 30.2°F | 333.8°F | 8.6°F

Figure 4.9. Requirement 1.2 Data

### 4.11. Objective 1. Verification

Objective 1 represented by the data shown in table 4.10. is the core objective of the doghouse heating system: “System will improve comfort within the doghouse based on external temperature conditions.”. This objective is a system-level evaluation of functional performance in environmental conditions. The test seeks to verify not only that the system responds correctly to temperature triggers, but that the outcome of this response—a significant increase in heating pad temperature—is reliable, repeatable, and effective in providing comfort.

To evaluate this objective, the fully integrated system was placed in a variety of cold environments, simulating the conditions of a Montana winter where doghouses might face temperatures well below freezing. The TMP36 ambient temperature sensor was positioned in free air within the test space to avoid heat contamination from the pad, while the second TMP36 sensor was adhered directly to the surface of the heating pad. This ensured continuous temperature monitoring of both the external environment and the system’s internal heating output. The temperature of the environment was used to place a multimeter against the pins of the TMP36.

Each test began with powering the system in a known cold ambient environment, either created through freezer testing (for sub zero conditions) or outdoor testing (for ranges from ~10°F to ~40°F). Once the ambient temperature fell within the system’s operational range (0°F to 40°F), the system automatically activated the heating pad using the control logic verified in Specification 1.1.1. The surface temperature of the pad was measured immediately upon activation by hand, confirming that it was not hot, and again a few minutes later. A total of five trials were conducted, each at different starting ambient temperatures, to test the responsiveness and effectiveness of the system across the full range of expected winter conditions.

The results from all five trials, shown below in Figure 4.10. Objective 1 Data, were consistent and demonstrated effective heating behavior across a wide range of cold environments. In each trial, tested across a large range of temperatures, the heating pad produced heat noticeable by hand every time. These results confirm that the system successfully creates a localized heat zone that would improve comfort for an animal within the doghouse. The objective ties together multiple layers of functionality: analog sensing, power regulation, digital control logic, PWM modulation, and thermal delivery. Its success validates not only the individual components but their interaction as a coherent, real-time autonomous control system.

| External Temperature as measured Temp Sensor (°F) | System outputting heat YES/NO
Trial 1 | 5.0°F | YES
Trial 2 | 64.4°F | NO
Trial 3 | 69.8°F | NO
Trial 4 | 30.2°F | YES
Trial 5 | 10.4°F | YES
Figure 4.10. Objective 1 Data

The results confirm repeatable and correct behavior across all trials. In each case where the ambient temperature was within the activation band, the system responded by enabling the heating element and increasing the pad temperature. In trials where ambient temperatures exceeded the deactivation threshold (>40 °F), the system correctly withheld heating output. No false positives or logical errors were observed.

From a system perspective, these outcomes demonstrate the effective interaction of all critical components: analog-to-digital conversion of temperature signals, conditional logic evaluation, pulse-width modulation (PWM) output control, and thermal actuation. The delay between activation condition and measurable pad heating remained consistent with prior subsystem-level timing tests, confirming that system response was not impeded by integration.

Moreover, the presence of consistent pad temperature elevation under cold conditions affirms the system’s ability to generate localized thermal zones sufficient for occupant comfort. These findings directly support the project’s thesis by validating the heating system’s capability to autonomously provide warmth in cold climates without user intervention.

Objective 1 was successfully verified. The integrated system met its top-level goal of providing temperature-triggered, effective, and self-regulated heating behavior. The data demonstrate that the system activates when expected, delivers appropriate heat output, and remains off when unnecessary—ensuring both energy efficiency and occupant safety. These results support the deployment of the system in real-world rural or off-grid applications where autonomous operation and environmental resilience are essential.

## Conclusions

### Project Motivation [AI]

The overarching goal of this project was to design, fabricate, and verify an autonomous heating system that could provide thermal comfort to a dog residing in an uninsulated shelter during Montana’s severe winter conditions. Specifically, the system was tasked with detecting ambient temperatures and activating a heating pad only when temperatures dropped into a defined operational window (0°F to 40°F), all while ensuring energy efficiency, safety, and reliability. This engineering challenge emerged from a well-defined real-world need outlined in Chapter 1: many dogs housed outdoors in areas face exposure to extreme cold without access to regulated, automated thermal control systems.

Upon completion of fabrication and integration, the final system was subjected to a comprehensive series of verification tests, each aligned with the specifications and requirements defined in the verification plan (see Chapter 4). These evaluations were conducted using controlled cold environments, multimeter measurements, infrared thermometry, and data logging to ensure repeatability.

Verification of Specification 1.2.2 confirmed that the TMP36 temperature sensors-maintained measurement accuracy within ±2 °F across a broad range of test conditions. Specification 1.1.1 was validated by demonstrating that the system reliably initiated heating only when the ambient temperature fell within the 0 °F to 40 °F range, with a ±2 °F tolerance. Specification 1.1.2 and Specification 1.1.3 was verified by measuring the system’s heating activation and deactivation response times, both of which consistently fell below the 60-second maximum defined in the system requirements..

At the requirement level, Requirement 1.1—which mandates autonomous heating in cold conditions—was confirmed through multi-trial heating pad response data. Requirement 1.2, addressing uninterrupted monitoring functionality, was satisfied through long-term ambient tracking under varying thermal environments.

This objective-aligned validation approach ensured that each subsystem—regulator, sensors, microcontroller, and heating element—was evaluated in the context of full-system behavior. The successful verification of all specifications and requirements affirms the system’s readiness for deployment in real-world applications.

The system reliably met its primary operational objective: to activate heating only when the ambient temperature was between 0°F and 40°F (±2°F). In the final verification testing, the heating activation and deactivation occurred at the appropriate boundaries without false triggers, indicating correct implementation of the control logic and successful integration of the analog-to-digital conversion routines. The heating pad, when engaged, showed consistent temperature increases confirming both its functionality and the integrity of the power delivery system. Furthermore, system latency was well within bounds—on average, the heating system activated within 15 to 25 seconds of crossing the operational threshold, significantly under the 60-second requirement. Similarly, deactivation occurred consistently within 35 seconds after exceeding the 40°F upper limit. These results affirm that the system is responsive enough to real-time temperature shifts while remaining within safe and effective operational margins.

Another key aspect of the project was demonstrating the system’s ability to operate under a wide range of environmental temperatures without failure. Component survivability was verified by comparing datasheet specifications with expected system exposure, and it was determined that all parts were rated well beyond the projected environmental extremes. This ensures that even in unusually cold snaps or milder-than-average winters, the system will remain fully functional. Additionally, the analog temperature sensors showed a deviation of less than 2°F when compared to an external IR thermometer, indicating high accuracy—especially for a cost-effective analog sensor like the TMP36. The reliability of this sensor input is foundational to the control loop and confirms the system’s credibility as a precision thermal regulator.

Beyond the quantitative test results, the project’s outcome can be evaluated based on system-level impact. The successful implementation of this autonomous heating system solves the initial problem described in Chapter 1: animals housed in cold, unregulated environments can now benefit from a compact, low-cost, low-power system that intelligently maintains warmth during dangerous temperature drops. The solution is especially significant for rural communities, animal shelters, and pet owners without access to insulated buildings or grid-connected heating solutions. This system can operate from a 12V DC supply—whether provided by a wall adapter, vehicle battery, or even a solar-powered battery bank—making it highly adaptable for off-grid or mobile applications.

### Future Work [AI]

While the doghouse heating system has achieved its defined goals and performed successfully through all verification stages, several opportunities exist to enhance the design’s performance, reliability, and long-term utility. These improvements could transform the current design into a fully deployable product with broader application, stronger user engagement, and increased operational flexibility.

An area for future work lies in expanding the system’s monitoring and control capabilities. Currently, the system operates autonomously, with internal logic determining when heating should be applied based on ambient temperature readings. While this fulfills the original objectives, incorporating a remote-control interface or mobile app would significantly improve the user experience. A remote or smartphone-based application could allow pet owners to check system status, receive alerts about critical temperature events, and adjust heating preferences manually if needed. For example, a user could override automatic behavior in specific cases, such as when a pet is ill or environmental conditions change unexpectedly. This remote interaction would also support broader adoption by enabling visibility and reassurance, especially for users who may not be physically present near the doghouse during extreme weather events.

To support ongoing evaluation and refinement, future development should also prioritize data collection and analysis. Enabling the system to log temperature data and heating behavior over time would allow users and developers to track performance trends, understand how the system responds to seasonal variations, and diagnose unexpected behaviors. These insights could guide further software improvements or environmental optimizations. Data access could be integrated with the aforementioned app or remote interface, providing users with tools to monitor internal and external temperatures, view recent heating cycles, and assess energy usage in a user-friendly dashboard.

From a control systems perspective, future improvements could include enhanced logic that accounts not only for instantaneous temperature readings, but also trends and rates of change. By incorporating predictive algorithms or learning-based adjustments, the system could optimize energy usage and thermal response more intelligently. This would allow the heater to anticipate environmental shifts and react preemptively, enhancing comfort while conserving power.

Another important area for potential refinement lies in power management. While the current version functions effectively on a fixed 12V power supply, making the system more versatile and power-aware would expand its applicability. For example, allowing the system to run on battery packs, with safeguards for low-voltage operation and optional recharging strategies, would support use in off-grid or portable scenarios. Integrating low-power design strategies into the firmware and hardware could also extend runtime significantly during winter deployments.

The system could also benefit from further development around multi-zone heating support. In larger enclosures, such as kennels with divided compartments or multi-pet structures, a future version of the system could regulate multiple heating pads independently. This would require changes to the control algorithm and additional sensing channels, but would greatly improve the solution’s flexibility and scalability.

While the current system represents a fully functional design that addresses the original problem, it also provides a strong springboard for future innovation. By adding remote control, enhancing durability, and expanding monitoring and power options, the system could evolve into a highly versatile and deployable technology—one capable of improving animal welfare in a variety of conditions and communities.

## Bill of Materials

### Bill of Materials

# | Part Name | Supplier | Unit Cost | Unit Amount | Total Cost

1 | OSHPARK PCB | DigiKey | $7.58 | 3 | $22.75
2 | Molex Connector(s) | DigiKey | $0.26 | 2 | $0.52
3 | LM2594MS-3.3/NOPB Buck Converter | DigiKey | $3.37 | 1 | $3.37
4 | AO3400A MOSFET | DigiKey | $0.46 | 1 | $0.46
5 | Capacitor 1uF | DigiKey | $0.10 | 2 | $0.20
6 | 4A Fuse | DigiKey | $0.50 | 1 | $0.50
7 | Molex Con Header | DigiKey | $0.37 | 1 | $0.37
8 | MSP430FR2310 | DigiKey | $1.65 | 1 | $1.65
9 | 10kΩ Resistor | DigiKey | $0.10 | 1 | $0.10
10 | 460Ω Resistor | DigiKey | $0.10 | 1 | $0.10
11 | TMP36 Temperature Sensors | DigiKey | $1.29 | 2 | $2.58
12 | DC Heating Pad | DigiKey | $33.99 | 1 | $33.99
13 | 12V Power Source | DigiKey | $20.99 | 1 | $20.99
14 | Shrink Tube | DigiKey | $2.50 | 1 | $2.50
Total Unit Cost | $90.08

## References

[1]
Alltrips, “AllTrips Bozeman Weather,” 2024. Available: https://www.bozemannet.com/weather/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,until%20the%20middle%20of%20October. [Accessed: 2024]
[2]
Chewy, “Dog Palace Insulated Heated Dog House,” 2021.
[3]
K. O. L.-K. O. H. P. Pad, “Dog Heating Pad,” 2020.
[4]
OCTROT, “OCTROT Heated Blanket,” 2021, Available: amazon.com
[5]
“Heat | Light Bulb Types.” Available: https://www.bulbs.com/learning/heat.aspx. [Accessed: Oct. 03, 2024]
[6]
“The Ultimate Guide to Heating and Lighting.” Available: https://www.zillarules.com/articles/the-ultimate-guide-to-lighting-and-heating. [Accessed: Oct. 03, 2024]
[7]
“Heat Pump Basics: How Heat Pumps Work & Common Types | The Super Blog.” Available: www.superradiatorcoils.com.
https://www.superradiatorcoils.com/blog/heat-pump-basics
[8]
“UL499, Electric Heating Appliances.” Available: https://www.intertek.com/standards-updates/ul-499-electric-heating-appliances/
[9]
“In-Depth: Interfacing TMP36 Temperature Sensor with Arduino,” Last Minute Engineers, Aug. 24, 2021. https://lastminuteengineers.com/tmp36-temperature-sensor-arduino-tutorial/

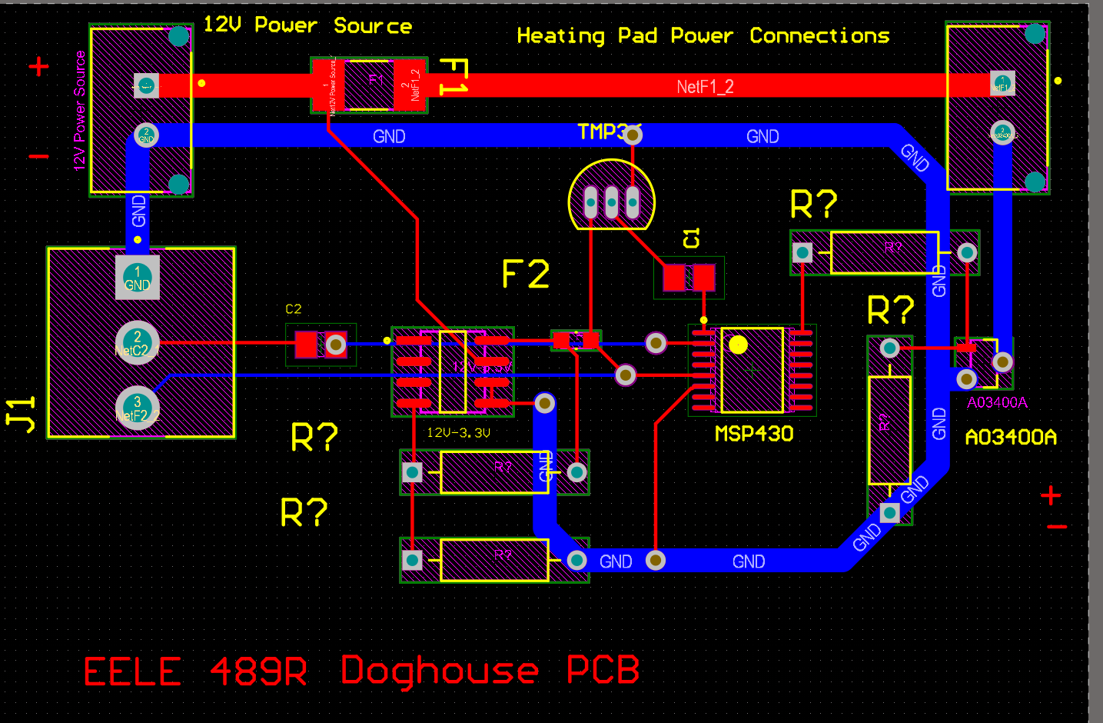
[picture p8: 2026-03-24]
TopViewPCB.png

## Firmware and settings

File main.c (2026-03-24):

#include <msp430.h>

#define AMBIENT_SENSOR_INPUT ADCINCH_1
#define HEATING_PAD_SENSOR_INPUT ADCINCH_0
#define HEATER_CONTROL BIT2

void initializeADC();
void initializeGPIO();
void initializePWM();
int readTemperature(int channel);
void controlHeater(int ambientTemp, int padTemp);
void setPWM(int dutyCycle);

int main(void) {
    WDTCTL = WDTPW | WDTHOLD;     // Stop watchdog timer
    PM5CTL0 &= ~LOCKLPM5;         // Unlock GPIOs

    initializeGPIO();
    initializeADC();
    initializePWM();

    while (1) {
        int ambientTempF = readTemperature(AMBIENT_SENSOR_INPUT);
        int padTempF = readTemperature(HEATING_PAD_SENSOR_INPUT);
        controlHeater(ambientTempF, padTempF);
        __delay_cycles(1000000);  // 1 second delay
    }
}

void initializeGPIO() {
    P1DIR |= HEATER_CONTROL;
    P1OUT &= ~HEATER_CONTROL;
}

void initializeADC() {
    ADCCTL0 &= ~ADCENC;
    ADCCTL0 = ADCSHT_2 | ADCON;
    ADCCTL1 = ADCSHP;
    ADCCTL2 = ADCRES;
    ADCCTL0 |= ADCENC;
}

void initializePWM() {
    TB0CCR0 = 999;
    TB0CCR1 = 0;
    TB0CTL = TBSSEL_2 | MC_1;
}

void setPWM(int dutyCycle) {
    if (dutyCycle <= 0) {
        // Turn PWM OFF
        TB0CCTL1 = 0;
        P1SEL0 &= ~HEATER_CONTROL;
        P1SEL1 &= ~HEATER_CONTROL;
        P1DIR  |= HEATER_CONTROL;
        P1OUT  &= ~HEATER_CONTROL;
    } else {
        // Set PWM mode on P1.2
        P1SEL0 |= HEATER_CONTROL;
        P1SEL1 &= ~HEATER_CONTROL;
        P1DIR  |= HEATER_CONTROL;
        TB0CCTL1 = OUTMOD_7;
        TB0CCR1 = (dutyCycle * TB0CCR0) / 100;
    }
}

int readTemperature(int channel) {
    ADCMCTL0 = channel;
    ADCCTL0 |= ADCSC;
    while (ADCCTL1 & ADCBUSY);

    int adcValue = ADCMEM0;
    float voltage = (adcValue * 3.3f) / 1023.0f;
    float tempC = (voltage - 0.5f) * 100.0f;
    return (int)((tempC * 9.0f / 5.0f) + 32.0f);
}

void controlHeater(int ambientTemp, int padTemp) {
    int lowerThreshold = 0 - 2;
    int upperThreshold = 40 + 2;
    int heatPadLimit = 115;

    if (ambientTemp > lowerThreshold && ambientTemp < upperThreshold) {
        if (padTemp < heatPadLimit) {
            int Tmin = 68;
            int Tmax = 115;
            int dutyCycle = 90 * (1 - ((padTemp - Tmin) / (float)(Tmax - Tmin)));
            setPWM(dutyCycle);
        } else {
            setPWM(0);
        }
    } else {
        setPWM(0);
    }
}
